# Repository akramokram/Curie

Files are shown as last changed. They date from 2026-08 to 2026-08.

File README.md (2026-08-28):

# Curie

### A social-assistance robot for focus, task initiation, and executive function

Curie is a physical desk companion designed to help people who struggle with task initiation, distraction, and maintaining focus — particularly people with ADHD or executive dysfunction.

Instead of putting another productivity app on a screen, Curie brings the interaction into the physical world.

It can talk, listen, move, react, remember, guide tasks, run focus sessions, and respond to what is happening around the user.

> **Curie is not a medical device and is not intended to diagnose, treat, or cure ADHD.**
> It is an experimental assistive technology project designed to reduce friction around everyday tasks and focus.



---

## ✨ What is Curie?

Curie is built around a simple idea:

**When starting a task is difficult, the solution shouldn't always be another notification, app, or productivity dashboard.**

Curie sits on the user's desk and acts as a persistent physical companion.

Rather than demanding attention, it is designed to provide small, low-friction interventions:

* Help break an overwhelming task into tiny first steps
* Start and manage focus sessions
* Provide gentle reminders
* Detect when the user has moved away from their workspace
* Detect potential phone/distraction activity
* Respond to voice commands
* Remember useful user information
* Provide a physical, expressive presence through its OLED face
* React through head movement, expressions, sound, and speech
* Provide breathing exercises
* Track focus-session performance and streaks

The goal is not to make the user "more productive" at all costs.

The goal is to **make starting and returning to a task easier.**

---

## 🧠 Designed around ADHD / Executive Dysfunction

Curie's interaction model is intentionally different from conventional productivity software.

Instead of:

> "You haven't completed your task."

Curie tries to reduce the barrier to starting:

> "Let's figure out the first tiny thing you need to do."

Its task-breakdown system is designed to turn an overwhelming task into **3–5 small, concrete first steps**.

Curie's AI personality is also deliberately designed not to shame the user for losing focus. The system prompt explicitly describes Curie as a calm support companion rather than a mascot or hype bot.

---

# 🤖 Features

## Voice Interaction

Curie can listen to the user through a microphone and respond using speech.

The software uses Groq's API for speech transcription and language-model interaction. The current implementation uses Whisper for audio transcription and Groq's OpenAI-compatible chat API for the AI layer.

API credentials are supplied by the user rather than hard-coded into the project.

---

## 📝 Task Breakdown

When the user is struggling to start something, Curie can turn the task into several extremely small actions.

For example:

**User:**

> "I need to finish my physics assignment."

**Curie:**

1. Open the assignment
2. Find the first unanswered question
3. Write down what the question is asking
4. Solve only that question

This is intended to reduce the activation energy required to begin.

---

## 🧠 Memory

Curie maintains a local SQLite database for:

* Recent conversation history
* User facts
* Daily focus statistics
* Brain-dump items

The database uses SQLite with WAL mode and locking to handle concurrent access.

Curie also includes a dedicated mechanism for clearing long-term user facts while preserving other information such as habits, streaks, trends, notes, and chat history.

---

## 📌 Brain Dump

Users can tell Curie about something they need to remember without creating a formal reminder.

Curie can store the item as a brain-dump note and retrieve the list later.

This is intended for the small thoughts that frequently interrupt a task:

> "I need to email my professor later."

Instead of switching apps and breaking focus, the user can simply tell Curie.

---

## ⏱️ Pomodoro / Focus Sessions



Curie includes an integrated focus timer with:

* Work sessions
* Break sessions
* Pause / resume
* Focus scoring
* Session statistics
* Streak tracking
* OLED timer animations
* Session-completion feedback

The physical OLED can display the focus state and final session score, including a small confetti animation after completion.

WhatsApp Image 2026-08-23 at 11 25 05 PM

---

## 🌬️ Breathing Exercise

WhatsApp Image 2026-08-23 at 11 25 05 PM (3)

Curie can guide the user through a timed breathing exercise.

The physical OLED transitions into a dedicated breathing interface and displays the remaining time.

---

## 👁️ Computer Vision

Curie uses the Arduino UNO Q's vision capabilities to detect objects in its environment.

The current software uses the Arduino `VideoObjectDetection` brick and processes detections for things such as:

* People
* Phones
* Mobile devices
* Other detected objects

The vision system maintains presence and phone-detection state, which can then be used by Curie's focus logic.

---

## 📱 Distraction Awareness

During a focus session, Curie can use vision information to track potential phone activity and whether the user is present.

This allows Curie to provide feedback without requiring the user to manually report that they became distracted.

The intention is not surveillance or punishment — the system is designed around gentle intervention and returning to the task.

---

## 👀 Expressive OLED Face

Curie's physical face is a 128×64 OLED display.

The Arduino firmware uses expressive eyes and multiple animation states to communicate Curie's state.

The OLED supports states including:

* Normal expressions
* Sleep
* Wake/startle
* Listening
* Processing
* Pomodoro
* Breathing
* Notifications
* Session scores
* Confetti
* Boot animation

The boot animation itself expands a ring and then spells out **CURIE** across the display.

---

## 🦾 Physical Movement

Curie's head currently uses a single pan axis.

The Arduino firmware controls the servo with interpolated movement rather than simply jumping between positions. The current implementation constrains the pan movement to approximately 45°–135°.
Curie can:

* Look left/right/up/down through coordinated eye and head behavior
* React to sound
* Look toward the user
* Move during conversations
* React to interactions
* Dance
* Startle/wake
* Perform idle movements

---

## 🫳 Physical Interaction

WhatsApp Image 2026-08-23 at 11 25 05 PM (1)

Curie includes touch inputs for physical interaction.

The current firmware defines separate touch inputs for:

* Petting
* Speaking / interaction

These inputs can trigger different behavioral responses from Curie.

---

# 🖥️ Web Interface

WhatsApp Image 2026-08-23 at 11 25 05 PM (2)

Curie also has a browser-based interface for controlling and monitoring the robot.

The interface includes a digital representation of Curie's face and controls for its different activities.

The interface currently includes functionality for:

* Chat
* Focus sessions
* Pomodoro controls
* Breathing exercises
* Habits
* Weekly trends
* Memory
* Settings
* Curie actions
* Camera status
* Hibernation
* Digital twin

The web interface also provides habit statistics such as Pomodoro score, phone pickups, and AFK events.

---

# 🔧 Hardware

curie breadboard schematic

Curie is built around the **Arduino UNO Q** platform.

### Main hardware

| Component | Purpose |
| --- | --- |
| Arduino UNO Q | Main computing platform |
| 128×64 I²C OLED | Physical face |
| Servo motor | Head pan movement |
| Microphone | Voice input |
| Speaker | Voice/audio output |
| Camera | Presence and object detection |
| Touch sensors | Physical interaction |
| 3D-printed body | Mechanical enclosure |
| Custom electronics | Power and signal distribution |

See [`hardware/`](hardware/) for the CAD files, schematic, and hardware documentation.

---

# 🔌 System Architecture

At a high level, Curie is split into two cooperating systems:

```text
                    ┌─────────────────────┐
                    │      CURIE USER     │
                    └──────────┬──────────┘
                               │
                 Voice / Touch / Presence
                               │
                               ▼
                    ┌─────────────────────┐
                    │    Arduino UNO Q    │
                    │                     │
                    │   Curie AI / App    │
                    │                     │
                    │  ┌───────────────┐  │
                    │  │ Voice + LLM   │  │
                    │  │ Memory        │  │
                    │  │ Vision        │  │
                    │  │ Focus System  │  │
                    │  └───────────────┘  │
                    └───────┬─────┬───────┘
                            │     │
                 RouterBridge     │
                            │     │
              ┌─────────────┘     └──────────────┐
              ▼                                  ▼
       ┌─────────────┐                    ┌─────────────┐
       │ Arduino MCU │                    │ Web UI      │
       │             │                    │             │
       │ OLED        │                    │ Digital     │
       │ Servo       │                    │ Twin        │
       │ Touch       │                    │ Controls    │
       └─────────────┘                    └─────────────┘
```

The Arduino-side firmware communicates with the application layer through Arduino RouterBridge.

---

# 📁 Repository Structure

```text
Curie/
│
├── README.md
├── LICENSE
├── .gitignore
│
├── docs/
│   ├── schematic.png
│   ├── architecture.png
│   └── images/
│
├── hardware/
│   ├── CAD/
│   │   ├── STEP/
│   │   ├── STL/
│   │   └── source/
│   └── BOM.md
│
├── software/
│   ├── curie-app/
│   │   ├── main.py
│   │   ├── index.html
│   │   └── ...
│   │
│   └── arduino/
│       ├── sketch.ino
│       ├── oled_driver.h
│       └── ...
│
├── media/
│   ├── demo.gif
│   └── screenshots/
│
└── releases/
    └── curie-app.zip
```

---

# 🚀 Getting Started

## Hardware

1. Assemble the Curie body using the provided CAD files.
2. Wire the electronics according to the schematic in [Curie Breadboard Schematic](hardware/curie%20breadboard%20schematic.png)
3. Connect the OLED, servo, touch sensors, microphone, speaker, and camera.
4. Install the required Arduino libraries.
5. Upload the Arduino firmware.

## Software

The Curie application runs on the Arduino UNO Q environment.

The application requires API credentials for external AI services used by the current implementation.

At minimum, configure:

```text
Groq API Key
Cartesia API Key
Cartesia Voice ID
```

Additional configuration includes:

```text
Location
Timezone
Language
Calendar configuration
```

**Do not commit API keys to GitHub.**

Use environment variables, a local configuration file excluded by `.gitignore`, or the application's settings mechanism.

---

# ⚠️ Current Status

Curie is an **active experimental project**.

The hardware, firmware, software, and interaction model are still being developed.

Some features may require specific Arduino UNO Q software versions, libraries, peripherals, or API services.

Expect things to change.

---

# 🛠️ Development

Curie consists of three major layers:

### Application Layer

Python application responsible for:

* AI interaction
* Voice
* Memory
* Vision
* Focus logic
* Statistics
* Web UI communication
* User context

### Interface Layer

HTML/CSS/JavaScript web interface providing:

* Digital twin
* Controls
* Statistics
* Settings
* Focus tools

### Hardware Layer

Arduino firmware responsible for:

* OLED rendering
* Eye animations
* Servo movement
* Touch interaction
* Physical reactions
* Hardware state

---

# 🤝 Contributing

Curie is intended to be an open hardware/software project.

Ideas, improvements, hardware modifications, interaction designs, and accessibility improvements are welcome.

If you build your own Curie or modify the design, I'd love to see it.

---

# 📜 License

This project is currently released under the terms of the license included in this repository.

See [`LICENSE`](LICENSE) for details.

---

# ❤️ Why Curie?

Productivity software usually asks the user to manage the tool.

Curie tries to do the opposite.

It sits beside you.

It notices.

It remembers.

It helps you start.

And when you get distracted, it doesn't tell you that you failed.

It just helps you come back.

**Curie is a physical interface between a person and the task they are trying to do.**

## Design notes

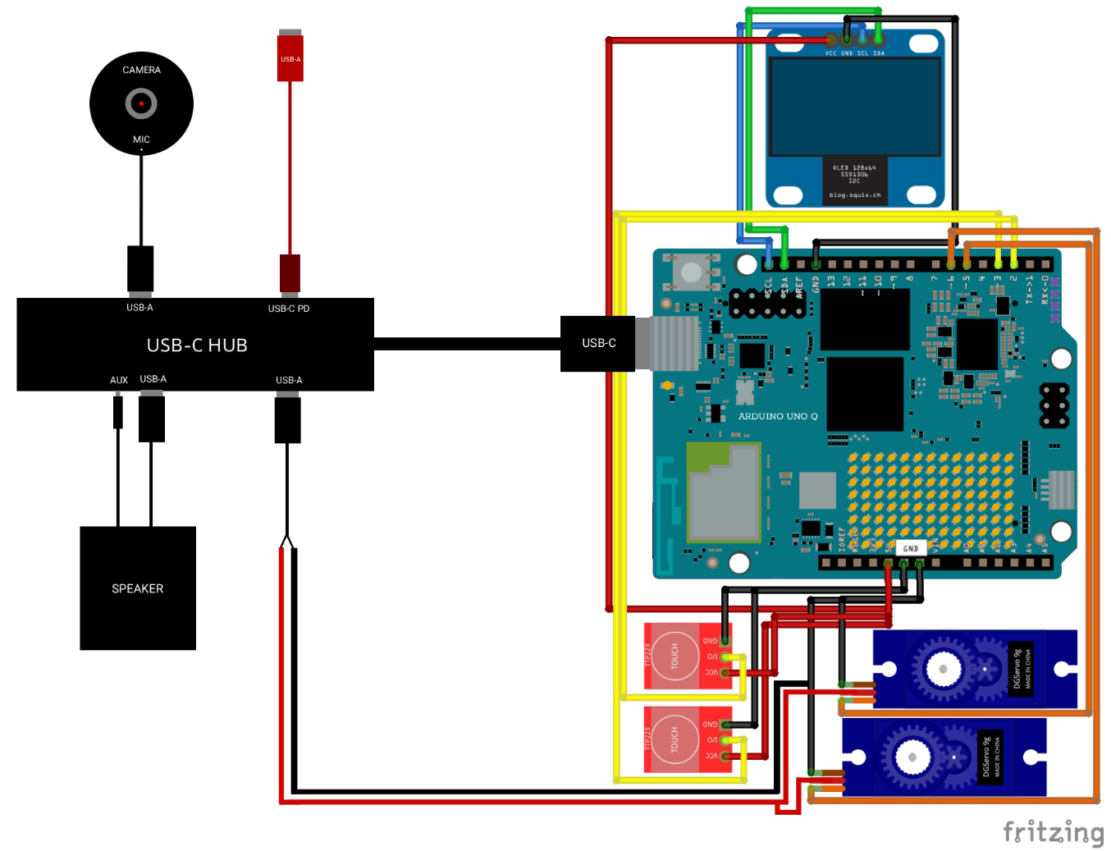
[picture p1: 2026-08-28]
hardware/curie breadboard schematic.png

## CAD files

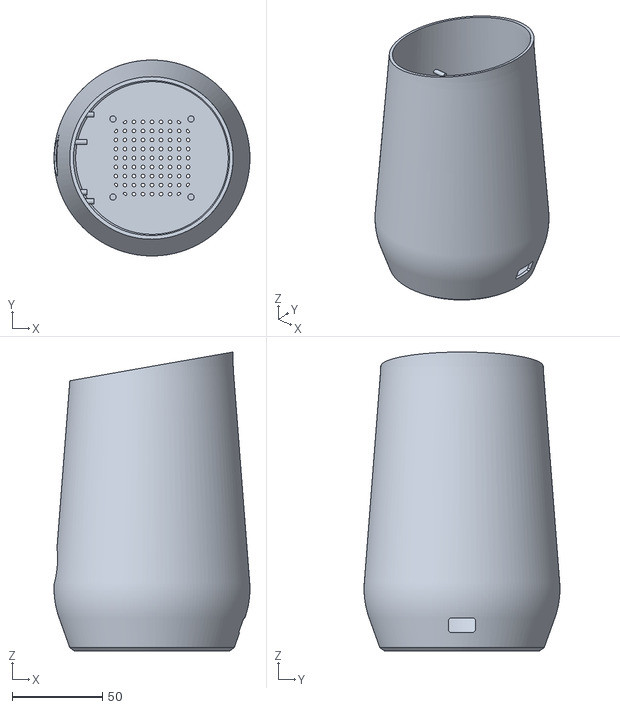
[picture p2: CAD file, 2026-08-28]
hardware/curie cad files/main body.stl
108.7 x 108.7 x 165.9

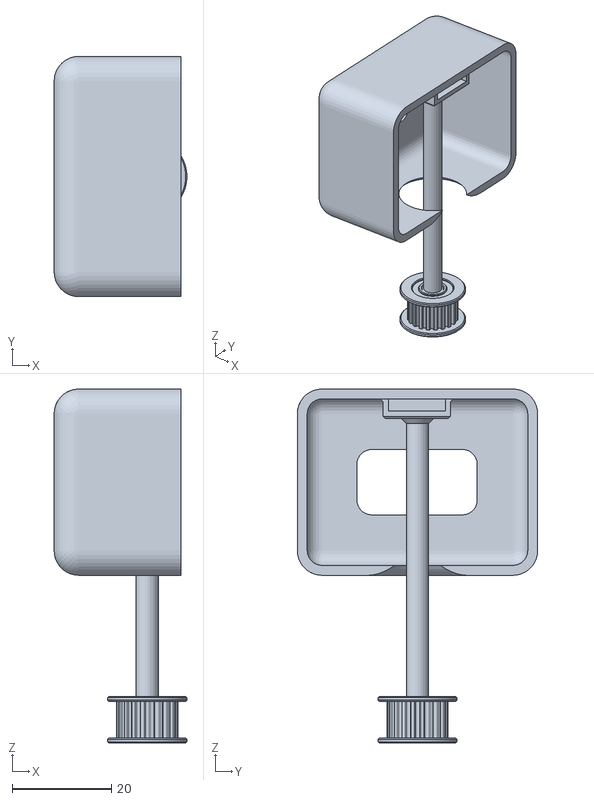
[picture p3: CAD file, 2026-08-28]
hardware/curie cad files/head final.stl
26.8 x 48.5 x 71.4

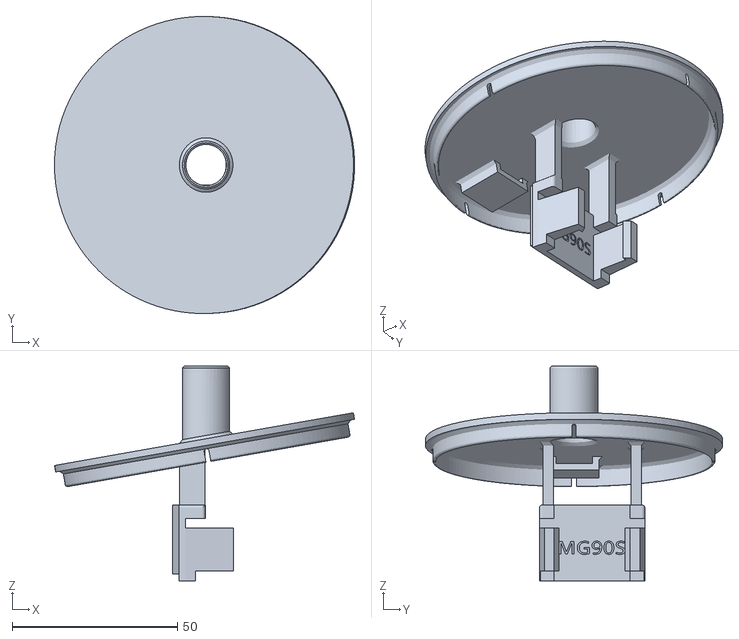
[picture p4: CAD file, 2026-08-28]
hardware/curie cad files/cover.stl
90.9 x 90.0 x 65.0

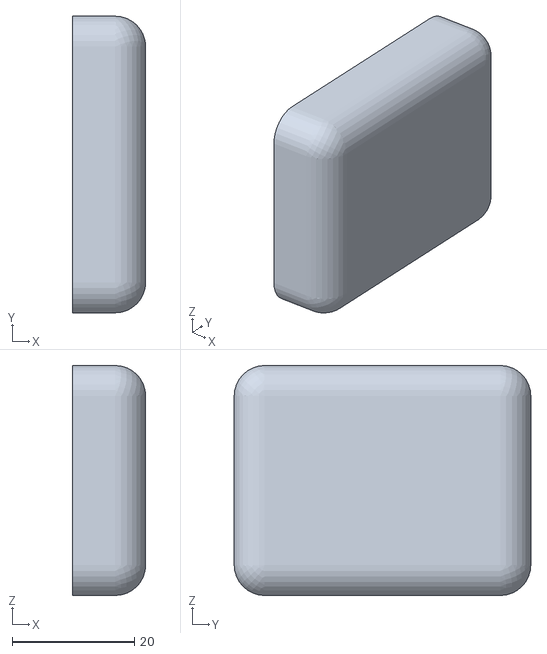
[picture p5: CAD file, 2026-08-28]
hardware/curie cad files/head cap.stl
12.0 x 48.5 x 37.6

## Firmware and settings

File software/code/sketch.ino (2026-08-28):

#include <Arduino.h>
#include <Wire.h>
#include <Servo.h>
#include "Adafruit_SSD1306.h"
#include <FluxGarage_RoboEyes.h>
#include <Arduino_RouterBridge.h>

#define SCREEN_WIDTH 128
#define SCREEN_HEIGHT 64
#define OLED_RESET -1

int indicatorState = 0; 
int dotCount = 0;
bool isAsleep = false;
int zzzFrame = 0;

bool isPomodoro = false;
bool isPomodoroBreak = false;
String pomodoroTime = "00:00";

int pomodoroAnimState = 0;
unsigned long pomoAnimTimer = 0;
bool pomodoroPaused = false;

bool isBreathingExercise = false;
String breathingTimeStr = "00:00";

bool isHibernatingMode = false;
bool isNotificationActive = false;
unsigned long notificationStartTime = 0;
bool reducedMotionMode = false;

// SCORE DISPLAY VARIABLES
bool isShowingScore = false;
int pomodoroFinalScore = 0;
unsigned long scoreDisplayTimer = 0;

Adafruit_SSD1306 display(SCREEN_WIDTH, SCREEN_HEIGHT, &Wire, OLED_RESET);
RoboEyes<Adafruit_SSD1306> roboEyes(display);

#define PIN_TOUCH_PET 2
#define PIN_TOUCH_SPEAK 3
#define PIN_SERVO_PAN 5
Servo panServo;

// KINEMATICS — single remaining pan axis
float currentPan = 90.0;
float startPan = 90.0;
float targetPan = 90.0;
unsigned long moveStartTime = 0;
float moveDuration = 1000.0;
int moveCurve = 0; 

unsigned long lastServoCalcTime = 0;
unsigned long lastServoActiveTime = 0;

// PETTING STATE TIMERS
unsigned long petStartTime = 0;
int petStage = 0; 
bool isReleasingPet = false;
unsigned long petReleaseTime = 0;
float petBasePan = 90.0f;

bool isListening = false;
bool isProcessing = false;

// STARTLE TIMERS
bool startleActive = false;
int startleStep = 0;
unsigned long startleTimer = 0;

int lookingDir = -1;
unsigned long lookDirTimer = 0;

unsigned long lastInteractionTime = 0;

// DANCE PARTY STATE VARIABLES
bool isDancing = false;
unsigned long lastDanceStepTime = 0; 
int danceState = 0; 
float dancePanRange = 0.0;
float maxDancePanRange = 25.0;
bool sweepRight = true;
int currentDanceType = 0;
unsigned long danceStartTime = 0;

// HUMOR
int humorLevel = 5;

// STREAK
int currentStreak = 0;

// POMODORO LIVE FOCUS LEVEL
int currentFocusLevel = -1;
unsigned long sweatUntil = 0;

// BREATHING STATE VARIABLES
unsigned long breathingStartTime = 0;
unsigned long breathingDuration = 120000;
bool breathingPaused = false;
unsigned long breathingPauseStart = 0;
unsigned long breathingPausedAccum = 0; 
unsigned long lastBreathingCycleTime = 0;
int breathingCycleState = 0; 
float breathEyeSize = 30.0;

unsigned long lastZzzTime = 0;
unsigned long lastDotTime = 0;

int minIdleSec = 4;
int maxIdleSec = 8;
unsigned long lastServoIdleMove = 0;
unsigned long nextServoIdleInterval = 4000;
unsigned long startupSuppressUntil = 0;
unsigned long lastSoundMovementTime = 0;

// DISPLAY TRANSITION ANIMATIONS
bool bootAnimationActive = false;
bool linuxReady = false;
unsigned long bootAnimationStart = 0;
unsigned long BOOT_ANIMATION_DURATION = 3400;

int breathingAnimState = 0;
unsigned long breathingAnimTimer = 0;

bool scoreConfettiActive = false;
unsigned long scoreConfettiStart = 0;

bool noddingActive = false;
unsigned long lastNodStepTime = 0;
int nodStep = 0;

bool headShakeActive = false;
unsigned long lastShakeStepTime = 0;
int shakeStep = 0;

unsigned long petActiveTime = 0;
unsigned long speakActiveTime = 0;
bool pomoPetHandled = false;
bool pomoSpeakHandled = false;

// IDLE MICRO-JITTER
float jitterOffsetPan = 0;
float jitterTargetPan = 0;
unsigned long lastJitterPick = 0;
unsigned long nextJitterInterval = 400;

// CONFETTI
bool confettiActive = false;
unsigned long confettiStartTime = 0;
int confettiTier = 0;
struct ConfettiParticle { float x, y, vx, vy; };
const int CONFETTI_COUNT = 14;
ConfettiParticle confetti[CONFETTI_COUNT];

// STREAK FLAME ICON
const unsigned char PROGMEM flameIcon8x8[] = {
  0x18, 0x3C, 0x7E, 0x7E, 0xFC, 0x7E, 0x3C, 0x18
};

void moveTo(float pPan, float duration, int curve) {
    if (reducedMotionMode) return;
    startPan = currentPan;
    targetPan = constrain(pPan, 45.0f, 135.0f);
    moveDuration = max(80.0f, duration);
    moveCurve = curve;
    moveStartTime = millis();
}

void set_indicator(int state) { 
    if (startleActive || isHibernatingMode || isNotificationActive) return; 
    indicatorState = state; 
}

void set_processing_state(int state) {
    if (isHibernatingMode) return;
    if (state == 1) {
        isProcessing = true;
        roboEyes.setPosition(N); 
        moveTo(constrain(currentPan + 15.0f, 45.0f, 135.0f), 800, 0); 
    } else {
        isProcessing = false;
        roboEyes.setPosition(DEFAULT);
        moveTo(currentPan, 500, 0); 
    }
}

void look_direction(int dir) {
    if (isAsleep || isPomodoro || isBreathingExercise || isHibernatingMode) return; 
    lookingDir = dir;
    lookDirTimer = millis();
    roboEyes.setHeight(30, 30);
    
    if(dir == 0) { moveTo(50, 800, 0); roboEyes.setPosition(W); }  
    if(dir == 1) { moveTo(130, 800, 0); roboEyes.setPosition(E); } 
    if(dir == 2) { moveTo(75, 800, 0); roboEyes.setPosition(N); }   
    if(dir == 3) { moveTo(105, 800, 0); roboEyes.setPosition(S); }  
}

void set_behavior_toggles(int s_en) { }

void set_curie_mood(int mood) {
    if (startleActive || isHibernatingMode || isDancing) return; 
    roboEyes.setHeight(30, 30); 
    if (mood == 1) { roboEyes.setMood(HAPPY); } 
    else if (mood == 2) { roboEyes.setMood(TIRED); } 
    else if (mood == 3) { roboEyes.setMood(ANGRY); } 
    else if (mood == 4) { roboEyes.setMood(DEFAULT); roboEyes.anim_confused(); } 
    else if (mood == 5) { roboEyes.setMood(HAPPY); roboEyes.anim_laugh(); } 
    else { roboEyes.setMood(DEFAULT); }
}

void done_speaking() {
    if (startleActive || isHibernatingMode || isDancing) return; 
    roboEyes.setHeight(30, 30);
    roboEyes.setMood(DEFAULT);
    moveTo(constrain(currentPan - 15.0f, 45.0f, 135.0f), 600, 0); 
}

void startBootAnimation() {
    linuxReady = true;
    bootAnimationActive = true;
    bootAnimationStart = millis();
    startupSuppressUntil = bootAnimationStart + BOOT_ANIMATION_DURATION;
    roboEyes.setIdleMode(OFF, 0, 0);
    roboEyes.setHeight(0, 0);
    roboEyes.setWidth(0, 0);
}

void update_pomodoro(int mins, int secs, int isBreak, int isPaused) {
    if (!isPomodoro) {
        isPomodoro = true;
        pomodoroAnimState = 1;
        pomoAnimTimer = millis();
        roboEyes.setIdleMode(OFF, 0, 0);
        roboEyes.setHeight(0, 0);
        roboEyes.setWidth(0, 0);
    }
    isPomodoroBreak = (isBreak == 1);
    pomodoroPaused = (isPaused == 1);
    char buf[10];
    sprintf(buf, "%02d:%02d", mins, secs);
    pomodoroTime = String(buf);
}

void stop_pomodoro() {
    isPomodoro = false;
    pomodoroAnimState = 0;
    roboEyes.setMood(DEFAULT);
    roboEyes.setHeight(30, 30);
    roboEyes.setWidth(30, 30);
    roboEyes.setSweat(false);
    roboEyes.setIdleMode(ON, 2, 2);
    currentFocusLevel = -1;
}

void start_breathing_exercise(int durationSec) {
    if (isHibernatingMode) return;
    if (isBreathingExercise) {
        breathingStartTime = millis();
        breathingDuration = (unsigned long)durationSec * 1000;
        breathingPaused = false;
        breathingPauseStart = 0;
        breathingPausedAccum = 0;
        return;
    }
    isBreathingExercise = true;
    breathingStartTime = millis();
    breathingDuration = (unsigned long)durationSec * 1000;
    breathingPaused = false;
    breathingPauseStart = 0;
    breathingPausedAccum = 0;
    lastBreathingCycleTime = millis();
    breathingCycleState = 0;
    breathEyeSize = 30.0;

    breathingAnimState = 1;
    breathingAnimTimer = millis();

    roboEyes.setMood(DEFAULT);
    roboEyes.setPosition(DEFAULT);
    roboEyes.setIdleMode(OFF, 0, 0);
    roboEyes.setHeight(0, 0);
    roboEyes.setWidth(0, 0);
}

void stop_breathing_exercise() {
    isBreathingExercise = false;
    breathingPaused = false;
    breathingPauseStart = 0;
    breathingPausedAccum = 0;
    breathingAnimState = 0;
    roboEyes.setHeight(30, 30);
    roboEyes.setWidth(30, 30);
    roboEyes.setPosition(DEFAULT);
    roboEyes.setAutoblinker(ON, 3, 2);
    roboEyes.setIdleMode(ON, 2, 2);
    Bridge.notify("breathing_finished");
}


void set_dance_state(int state) {
    if (isBreathingExercise || isHibernatingMode) return; 
    isDancing = (state == 1);
    if (isDancing) {
        roboEyes.setMood(HAPPY);
        roboEyes.setAutoblinker(OFF); 
        lastDanceStepTime = millis();
        danceState = 0;
        dancePanRange = 0.0;
        sweepRight = true;
        currentDanceType = random(0, 3);
        danceStartTime = millis();
    } else {
        roboEyes.setMood(DEFAULT);
        roboEyes.setAutoblinker(ON, 3, 2); 
        moveTo(90, 1000, 0);
    }
}

void trigger_startle() {
    if (isHibernatingMode) return;
    if (millis() - lastServoActiveTime < 1500) return; 
    
    isAsleep = false;
    startleActive = true;
    startleStep = 0;
    
    roboEyes.setMood(TIRED); 
    roboEyes.setHeight(30, 15);
    roboEyes.setIdleMode(ON, 2, 2);
    
    moveTo(90, 150, 2); 
    
    headShakeActive = true;
    shakeStep = 0;
    lastShakeStepTime = millis();
    
    startleTimer = millis();
    Bridge.notify("woke_up"); 
}

void trigger_sound_movement() {
    if (isHibernatingMode || isAsleep || isPomodoro || isBreathingExercise || reducedMotionMode) return;
    if (millis() - lastSoundMovementTime < 5000) return;
    if (millis() - lastServoActiveTime < 700) return;
    lastSoundMovementTime = millis();
    float basePan = constrain(currentPan + 10.0, 55.0, 125.0);
    moveTo(basePan, 250, 0);
}

void set_idle_config(int minSec, int maxSec) {
    minIdleSec = minSec; maxIdleSec = maxSec;
    nextServoIdleInterval = random(minIdleSec * 1000, maxIdleSec * 1000);
}

void startConfetti(int tier) {
    if (isHibernatingMode) return;
    confettiActive = true;
    confettiTier = tier;
    confettiStartTime = millis();
    for (int i = 0; i < CONFETTI_COUNT; i++) {
        float angle = random(0, 360) * PI / 180.0;
        float speed = random(20, tier == 1 ? 55 : 40) / 10.0;
        confetti[i].x = 64; confetti[i].y = 32;
        confetti[i].vx = cos(angle) * speed;
        confetti[i].vy = sin(angle) * speed;
    }
}

void reactToPhone(int tier) {
    if (isHibernatingMode || startleActive || isBreathingExercise) return;
    if (tier == 1) {
        moveTo(currentPan + (currentPan < 90 ? -10 : 10), 300, 0);
    } else if (tier == 2) {
        roboEyes.setMood(DEFAULT);
        moveTo(constrain(currentPan + 15.0f, 45.0f, 135.0f), 400, 0);
    } else {
        roboEyes.setSweat(true);
        sweatUntil = millis() + 6000;
        moveTo(constrain(currentPan - 10.0f, 45.0f, 135.0f), 250, 0);
    }
}

void setup() {
    Bridge.begin();
    Bridge.provide("start_boot_animation", [](int state) {
        if (state) startBootAnimation();
    });
    Bridge.provide("set_idle_config", set_idle_config);
    Bridge.provide("set_curie_mood", set_curie_mood); 
    Bridge.provide("set_indicator", set_indicator); 
    Bridge.provide("set_behavior_toggles", set_behavior_toggles);
    Bridge.provide("look_direction", look_direction); 
    Bridge.provide("set_processing_state", set_processing_state); 
    Bridge.provide("done_speaking", done_speaking); 
    Bridge.provide("trigger_startle", trigger_startle);
    Bridge.provide("trigger_sound_movement", trigger_sound_movement); 
    Bridge.provide("set_dance_state", set_dance_state); 
    Bridge.provide("update_pomodoro", update_pomodoro); 
    Bridge.provide("stop_pomodoro", stop_pomodoro); 
    Bridge.provide("start_breathing_exercise", start_breathing_exercise);
    Bridge.provide("stop_breathing_exercise", stop_breathing_exercise);
    Bridge.provide("pause_breathing_exercise", [](int state) {
        if (state == 1) {
            if (!breathingPaused) { breathingPaused = true; breathingPauseStart = millis(); }
        } else {
            if (breathingPaused) {
                if (breathingPauseStart > 0) breathingPausedAccum += millis() - breathingPauseStart;
                breathingPauseStart = 0;
                breathingPaused = false;
                lastBreathingCycleTime = millis();
            }
        }
    });

    Bridge.provide("update_streak", [](int streak) { currentStreak = streak; });
    Bridge.provide("set_humor_level", [](int h) { humorLevel = h; });
    Bridge.provide("set_focus_level", [](int tier) { currentFocusLevel = tier; });
    Bridge.provide("react_phone", reactToPhone);
    Bridge.provide("set_reduced_motion", [](int state){ reducedMotionMode = (state == 1); });
    Bridge.provide("celebrate", [](int tier) {
        startConfetti(tier);
        roboEyes.setMood(HAPPY);
        moveTo(constrain(currentPan - 10.0f, 45.0f, 135.0f), 250, 0);
    });

    Bridge.provide("set_hibernate_mode", [](int state) {
        isHibernatingMode = (state == 1);
        if (isHibernatingMode) {
            moveTo(constrain(currentPan + 15.0f, 45.0f, 135.0f), 1000, 0); 
            roboEyes.setIdleMode(OFF, 0, 0);  
        } else {
            moveTo(90, 1000, 0);
            startBootAnimation();
            lastInteractionTime = millis();
        }
    });

    Bridge.provide("set_sleep_state", [](int state) {
        isAsleep = (state == 1);
        if (isAsleep) {
            moveTo(constrain(currentPan + 15.0f, 45.0f, 135.0f), 3000, 0);
            roboEyes.setHeight(2, 2);
            roboEyes.setWidth(30, 30);
            roboEyes.setAutoblinker(OFF, 0, 0);
            roboEyes.setIdleMode(OFF, 0, 0);
        } else {
            roboEyes.setHeight(30, 30);
            roboEyes.setWidth(30, 30);
            roboEyes.setPosition(DEFAULT);
            roboEyes.setAutoblinker(ON, 3, 2);
            roboEyes.setIdleMode(ON, 2, 2);
            roboEyes.setMood(DEFAULT);
            moveTo(90, 500, 0);
        }
    });

    Bridge.provide("trigger_notification", [](int state) {
        isNotificationActive = true;
        notificationStartTime = millis();
        indicatorState = 3; 
    });

    Bridge.provide("show_pomodoro_score", [](int score) {
        isShowingScore = true;
        pomodoroFinalScore = score;
        scoreDisplayTimer = millis();
        scoreConfettiActive = true;
        scoreConfettiStart = millis();
        confettiActive = false;
    });

    pinMode(PIN_TOUCH_PET, INPUT);
    pinMode(PIN_TOUCH_SPEAK, INPUT);
    
    delay(1000); 
    Wire.begin();
    delay(100); 
    
    display.begin(SSD1306_SWITCHCAPVCC, 0x3C);
    display.clearDisplay();
    display.display();
    
    roboEyes.begin(SCREEN_WIDTH, SCREEN_HEIGHT, 100); 
    roboEyes.setPosition(DEFAULT);
    roboEyes.setAutoblinker(ON, 3, 2);
    roboEyes.setIdleMode(ON, 2, 2);
    roboEyes.setCuriosity(true);

    linuxReady = false;
    display.clearDisplay();
    display.display();

    lastInteractionTime = millis();
    currentPan = 90.0;
    targetPan = 90.0;
    startPan = 90.0;
    startupSuppressUntil = bootAnimationStart + BOOT_ANIMATION_DURATION;
}
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

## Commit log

2026-08-28 Add initial list of materials to BOM
2026-08-28 Update print statement from 'Hello' to 'Goodbye'
2026-08-28 Add initial Arduino sketch with multiple features
    Initial implementation of the sketch for Arduino, including setup for display, servo control, and various behaviors such as pomodoro timer, breathing exercises, and interaction handling.
2026-08-28 Add OLED display driver header file
2026-08-28 Add installation requirements for Arduino app Lab
    List required bricks for Arduino app Lab installation.
2026-08-28 Add list of required libraries for Arduino App Lab
    List required libraries for Arduino App Lab installation.
2026-08-28 Update BOM with detailed list of materials
2026-08-28 Update schematic file path in README
2026-08-28 Update link format for hardware schematic in README
